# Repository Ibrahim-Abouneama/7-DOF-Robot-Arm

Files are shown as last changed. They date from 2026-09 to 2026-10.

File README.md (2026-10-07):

# 🦾 7-DOF Robot Arm Hotkey & Web Controller

A high-performance robotic arm control suite featuring zero-glitch ESP32 firmware, linear slew motion profiling, browser-based hotkey control (USB WebSerial), and complete 3D CAD models.

---

## 🌟 Highlights

- **Zero-Glitch Direct PCA9685 Driver**: Custom bare-metal I2C driver eliminating comparator glitches, phase-staggered pulse timing to prevent peak power surges, and automatic register recovery without resetting joint positions.
- **Linear Slew Profile**: Smooth, non-blocking motion ramping at user-selectable speeds (20°/s to 120°/s) to protect gearboxes and eliminate jerks.
- **Dual Connectivity Modes**:
  - **USB Mode**: Direct low-latency WebSerial communication via Chrome/Edge/Opera.
- **Full Keyboard Hotkeys**: Control all 6 axes + claw simultaneously with configurable step sizes and continuous drive.
- **Complete CAD Package**: Includes 12 universal 3D-printable `.STEP` models and the SolidWorks master assembly (`RobotArm_Assembly.SLDASM`).

---

## 📂 Repository Structure

```text
├── cad/
│   ├── assembly/
│   │   └── RobotArm_Assembly.SLDASM    # SolidWorks master assembly
│   └── step/                           # 12 3D-printable STEP models
│       ├── Base.STEP
│       ├── Claw.STEP
│       ├── Claw 1.STEP
│       ├── Claw Holder.STEP
│       ├── Claw Link.STEP
│       ├── Gear.STEP
│       ├── Gear 1.STEP
│       ├── Rod 0.STEP
│       ├── Rod 1.STEP
│       ├── Rod2.STEP
│       ├── Shoulder.STEP
│       └── Wrist.STEP
├── firmware/
│   └── robot_arm_v3/                   # USB WebSerial firmware
│       └── robot_arm_v3.ino
├── controller/
│   └── servo_hotkeys_v2.html           # USB WebSerial controller UI
├── start_hotkey_controller.bat         # 1-click launcher for USB mode
├── .gitignore
└── README.md
```

---

## ⚡ Hardware & Wiring

### Components
- **Microcontroller**: ESP32 Development Board (30-pin or 38-pin)
- **PWM Driver**: PCA9685 16-Channel 12-Bit I2C Servo Driver
- **Servos**: MG996R / MG995 (High-Torque for Base, Shoulder, Elbow) + SG90 (Wrist & Gripper)
- **Power Supply**: Dedicated 5V-6V 4A-10A DC Power Supply (connected to PCA9685 green terminal)

> ⚠️ **Warning**: Never power the servos from the ESP32 5V/3.3V pins. Always use a dedicated power supply for the PCA9685 screw terminal with common GND shared with the ESP32.

### Pinout
| ESP32 Pin | PCA9685 Pin | Description |
|---|---|---|
| **GPIO 21** | **SDA** | I2C Data Line |
| **GPIO 22** | **SCL** | I2C Clock Line |
| **3V3** | **VCC** | Logic Power (3.3V) |
| **GND** | **GND** | Common Ground |
| — | **V+ (Terminal)** | 5V - 6V DC High-Current Power |

### Servo Channels & Calibrated Defaults
| PCA9685 Channel | Joint Name | Min Limit | Max Limit | Home Angle | Typical Servo |
|:---:|---|:---:|:---:|:---:|:---:|
| **CH 15** | Base Rotation | 0° | 180° | **90°** | MG996R |
| **CH 14** | Shoulder Pitch | 10° | 170° | **44°** | MG996R |
| **CH 13** | Elbow Pitch | 10° | 170° | **130°** | MG996R |
| **CH 12** | Forearm Pitch | 10° | 170° | **90°** | MG996R / SG90 |
| **CH 11** | Wrist Roll | 0° | 180° | **90°** | SG90 |
| **CH 10** | Wrist Pitch | 10° | 170° | **90°** | SG90 |
| **CH 9** | Gripper Claw | 0° | 90° | **0°** (Open) | SG90 |

---

## ⌨️ Keyboard Hotkey Map
| Key Binding | Function | Direction / Action |
|:---:|---|---|
| <kbd>Q</kbd> / <kbd>A</kbd> | Base Yaw | Rotate Left / Right |
| <kbd>W</kbd> / <kbd>S</kbd> | Shoulder | Tilt Up / Down |
| <kbd>E</kbd> / <kbd>D</kbd> | Elbow | Tilt Up / Down |
| <kbd>R</kbd> / <kbd>F</kbd> | Forearm | Tilt Up / Down |
| <kbd>T</kbd> / <kbd>G</kbd> | Wrist Roll | Rotate CW / CCW |
| <kbd>Y</kbd> / <kbd>H</kbd> | Wrist Pitch | Tilt Up / Down |
| <kbd>U</kbd> / <kbd>J</kbd> | Gripper | Close / Open Claw |
| <kbd>←</kbd> / <kbd>→</kbd> | Active ch nudge | Nudge Selected Joint (− / +) |
| <kbd>[</kbd> / <kbd>]</kbd> | Step size | Cycle Step Size (1°, 5°, 10°, 20°) |
| <kbd>Space</kbd> | Home pose | Auto-align arm to default posture |
| <kbd>1</kbd> – <kbd>7</kbd> | Select ch | Select Active Joint (CH 15 to CH 9) |
| <kbd>Esc</kbd> | **E-Stop** | Instantly freeze all joints / Toggle resume |

---

## 🚀 Getting Started

### 1. Flash the ESP32 Firmware
1. Open the [Arduino IDE](https://www.arduino.cc/en/software).
2. Install the **esp32** board package (`Tools` > `Board` > `Boards Manager...`).
3. Select your ESP32 board and COM port.
4. Open:
   - `firmware/robot_arm_v3/robot_arm_v3.ino` (for USB WebSerial)
5. Click **Upload**.

### 2. Launch the Controller

1. Connect ESP32 to your PC via USB.
2. Double-click `start_hotkey_controller.bat` (opens `controller/servo_hotkeys_v2.html` in Chrome/Edge/Opera).
3. Click **Connect Serial**, select your ESP32 COM port (115200 baud).
4. Use your keyboard or on-screen sliders to control the arm.

---

## 🖨️ 3D Printing & CAD

All 12 `.STEP` models in `cad/step/` can be directly imported into any modern slicer:
- **Recommended Material**: PLA+ or PETG
- **Infill**: 30% - 50% Gyroid or Grid (higher infill recommended for `Base.STEP`, `Shoulder.STEP`, and `Rod 0.STEP`)
- **Perimeters/Walls**: 4-5 walls for structural rigidity
- **Assembly CAD**: `cad/assembly/RobotArm_Assembly.SLDASM` can be opened in Dassault Systèmes SolidWorks.

---

## 📄 License

MIT License. Free to use, modify, and distribute for personal and commercial robotics projects.

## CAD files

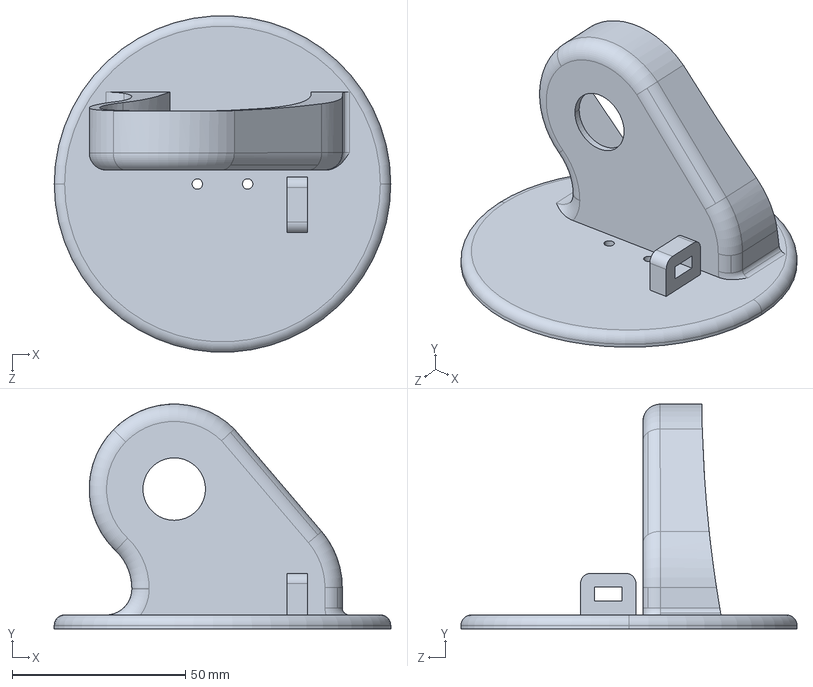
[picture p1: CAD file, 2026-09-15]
cad/step/Shoulder.STEP
97.0 x 64.7 x 96.8 mm

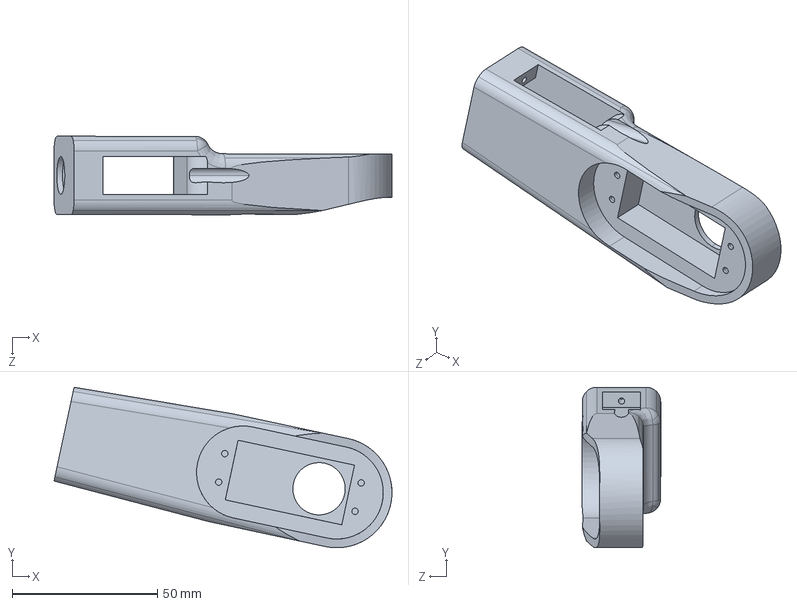
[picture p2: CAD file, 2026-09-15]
cad/step/Rod2.STEP
116.3 x 55.2 x 27.0 mm

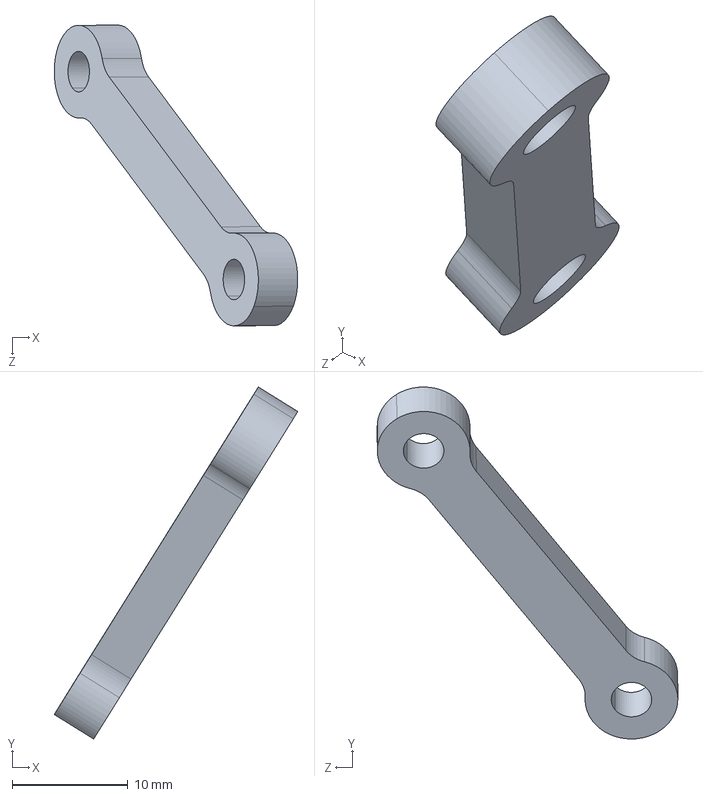
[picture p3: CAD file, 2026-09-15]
cad/step/Claw Link.STEP
21.0 x 30.4 x 25.9 mm

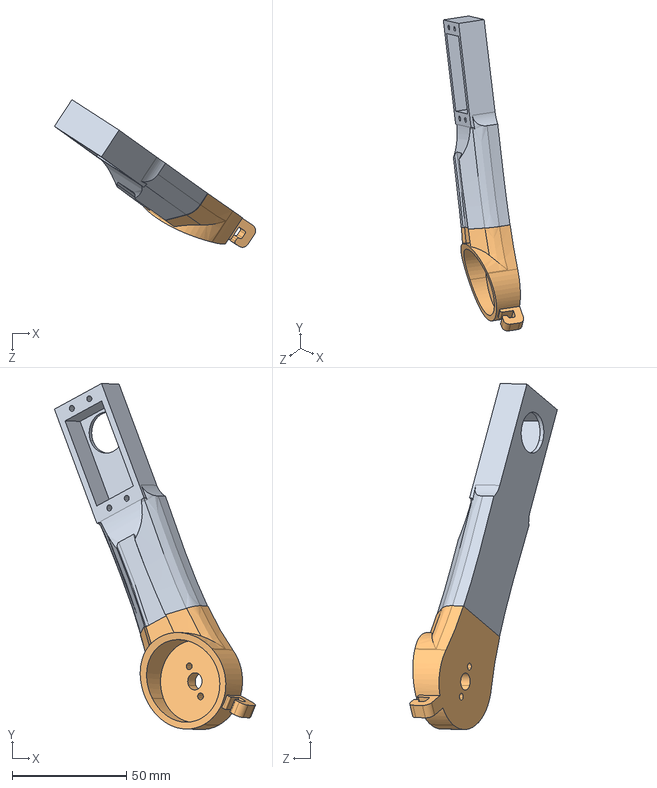
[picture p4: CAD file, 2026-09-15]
cad/step/Rod 0.STEP
88.1 x 151.4 x 64.6 mm

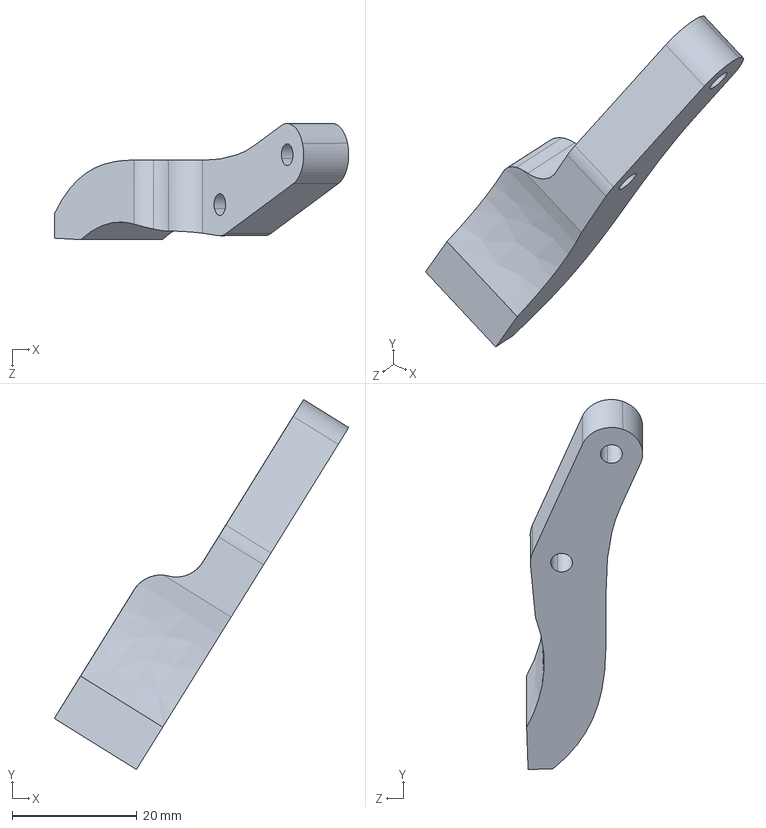
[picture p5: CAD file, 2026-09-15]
cad/step/Claw.STEP
47.2 x 59.3 x 18.6 mm

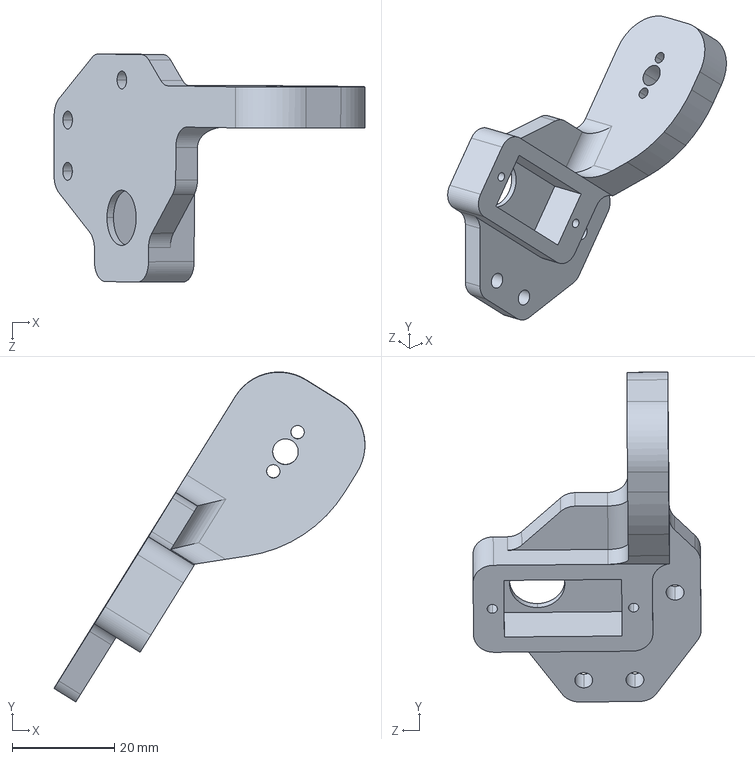
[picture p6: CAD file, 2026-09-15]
cad/step/Claw Holder.STEP
60.7 x 64.4 x 44.5 mm

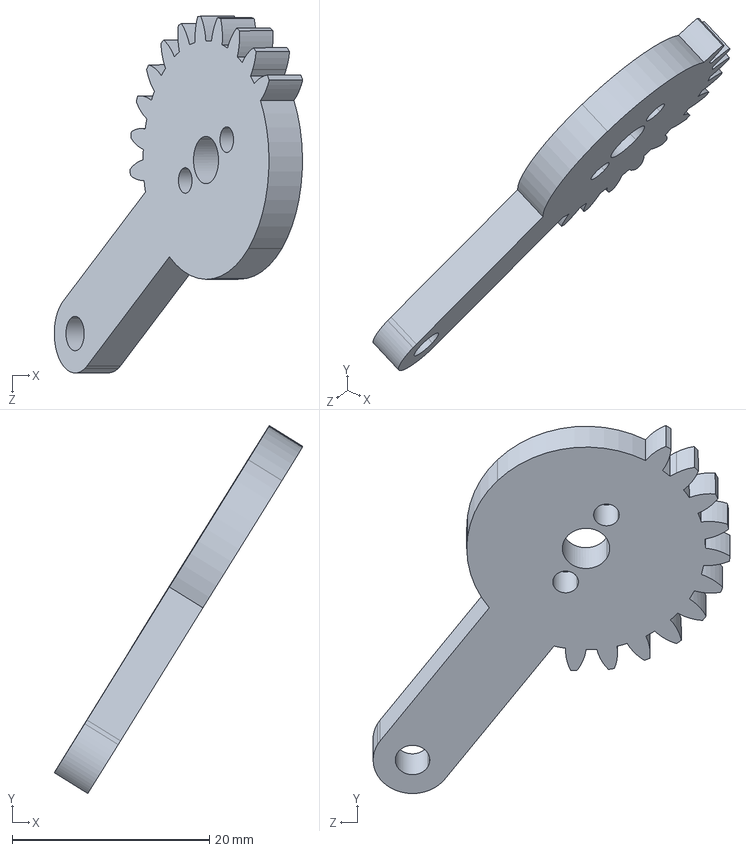
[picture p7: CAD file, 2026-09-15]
cad/step/Gear.STEP
25.2 x 37.3 x 36.2 mm

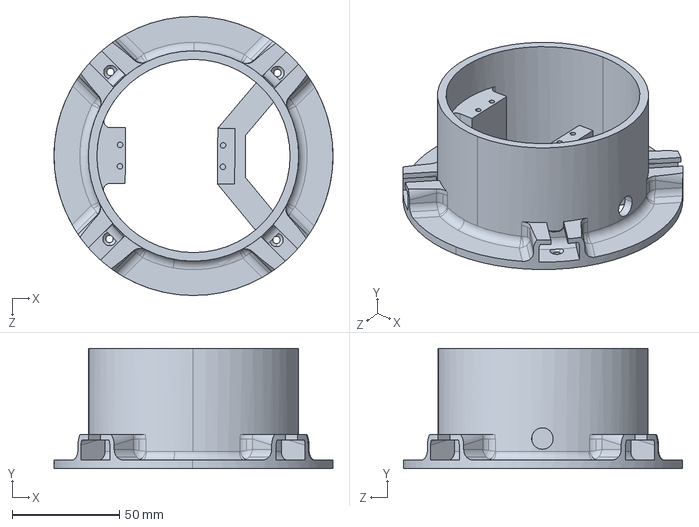
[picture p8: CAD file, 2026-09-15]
cad/step/Base.STEP
130.0 x 56.0 x 130.0 mm

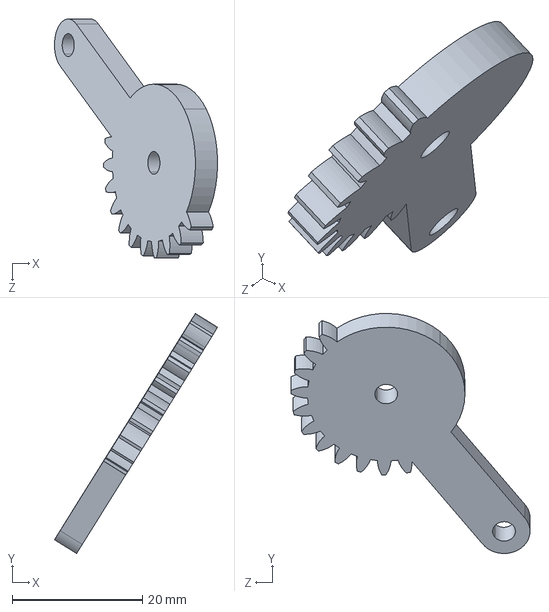
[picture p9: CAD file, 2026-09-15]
cad/step/Gear 1.STEP
25.0 x 36.9 x 36.7 mm

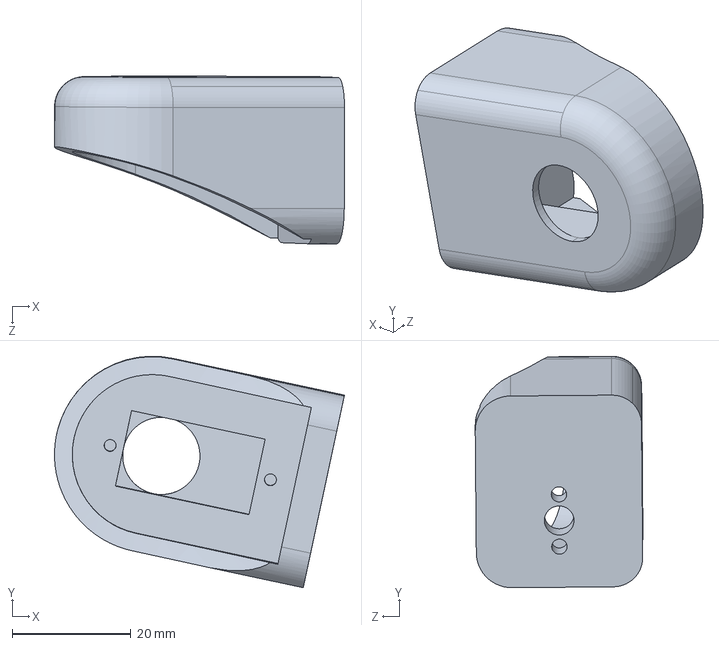
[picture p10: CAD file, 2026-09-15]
cad/step/Wrist.STEP
48.8 x 38.9 x 28.2 mm

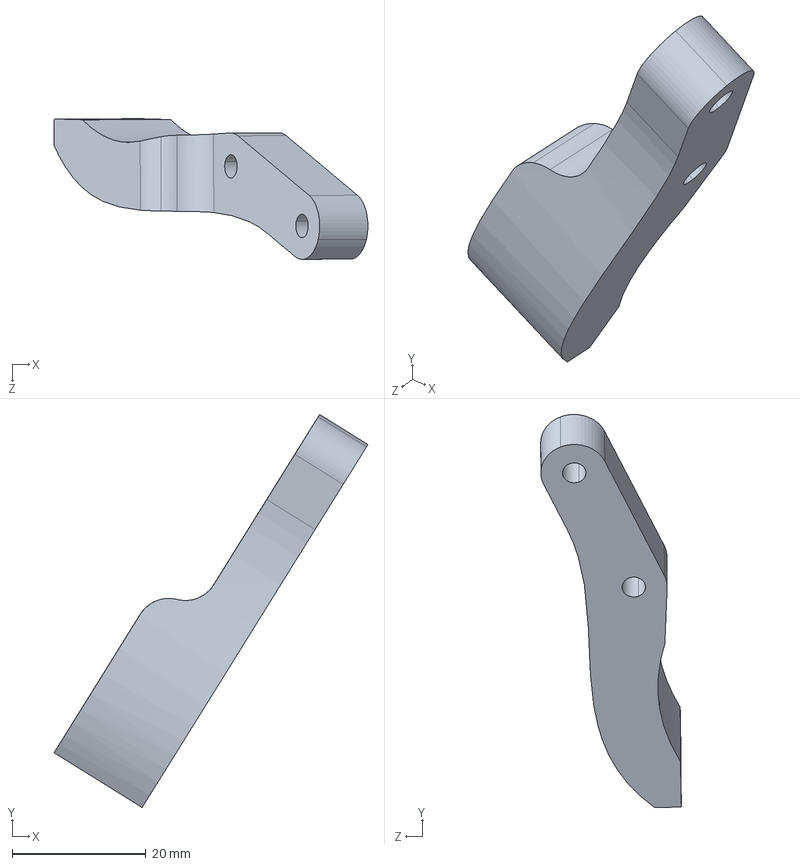
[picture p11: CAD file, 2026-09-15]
cad/step/Claw 1.STEP
46.9 x 58.8 x 21.0 mm

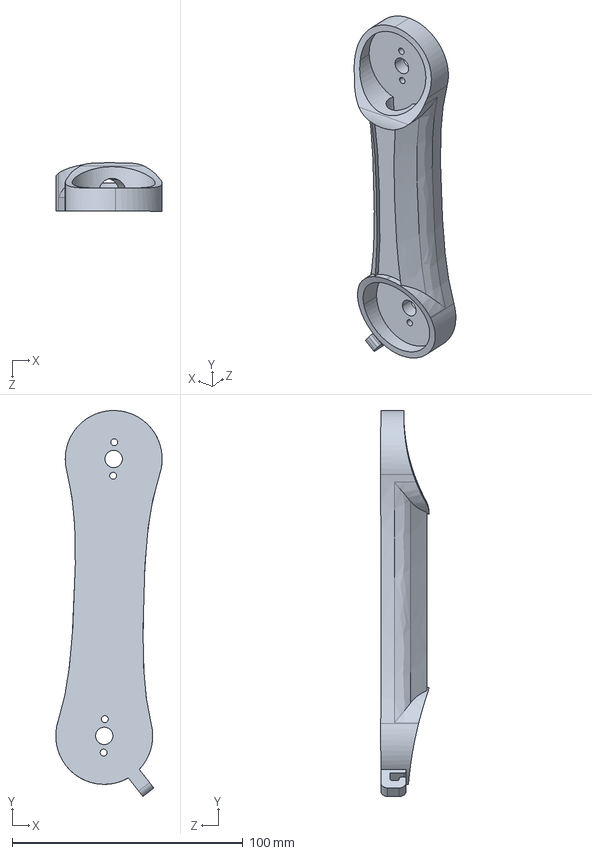
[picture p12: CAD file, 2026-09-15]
cad/step/Rod 1.STEP
46.1 x 167.2 x 21.0 mm

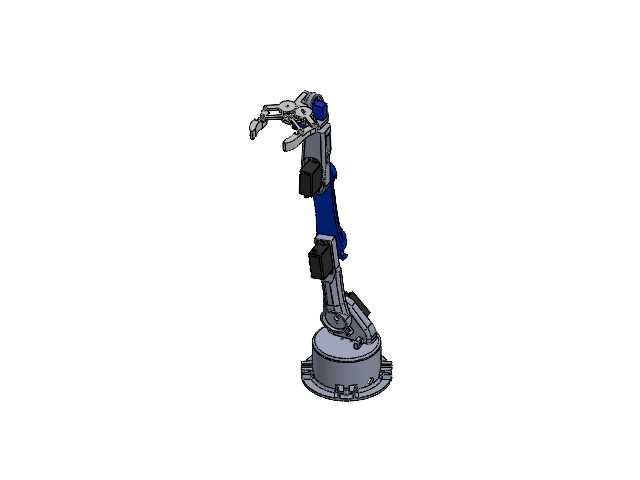
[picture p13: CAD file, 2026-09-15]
cad/assembly/RobotArm_Assembly.SLDASM
MG996R Servo
SG90
SG90 1
MG996R Servo 1 x 2
MG996R Servo 2
SG90 2
Claw
Claw Link x 2
Gear
Claw Holder
Claw 1
Gear 1
Base
Wrist
Rod2
Rod 1
Pin
Shoulder
Rod 0

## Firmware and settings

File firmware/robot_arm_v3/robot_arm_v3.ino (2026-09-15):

// ============================================================================
//  ESP32 ROBOT ARM CONTROLLER v3.0 — GROUND-UP REBUILD
//  Channels: 15 (Base) → 9 (Gripper)
//  Protocol: $CMD,arg1,arg2*\n  (115200 baud)
//  Driver:   Direct PCA9685 register access via Wire.h — ZERO external libs
// ============================================================================
//
//  HARDWARE WIRING:
//    ESP32 GPIO 21 (SDA) → PCA9685 SDA
//    ESP32 GPIO 22 (SCL) → PCA9685 SCL
//    ESP32 GND            → PCA9685 GND  → Power Supply GND (common ground!)
//    Power Supply 5-6V    → PCA9685 V+ screw terminal
//    PCA9685 OE pin       → GND (active low = outputs enabled)
//
//  CHANNEL MAP:
//    CH 15: Base Turntable Yaw       (MG996R)   0-180°
//    CH 14: Shoulder Pitch (Grey)    (MG996R)  10-170°
//    CH 13: Elbow Pitch (Blue)       (MG996R)  10-170°
//    CH 12: Forearm Pitch (Grey)     (MG996R)  10-170°
//    CH 11: Wrist Roll              (MG90S)    0-180°
//    CH 10: Wrist Pitch             (MG90S)   10-170°
//    CH  9: Gripper Claw            (SG90)     0-90°
// ============================================================================

#include <Wire.h>

// ─── Pin & Address Configuration ────────────────────────────────────────────
#define I2C_SDA       21
#define I2C_SCL       22
#define PCA_ADDR      0x40

// ─── PCA9685 Registers ─────────────────────────────────────────────────────
#define REG_MODE1     0x00
#define REG_MODE2     0x01
#define REG_LED0_ON_L 0x06
#define REG_PRESCALE  0xFE

// ─── PCA9685 Bits ───────────────────────────────────────────────────────────
#define MODE1_AI      0x20    // Auto-increment
#define MODE1_SLEEP   0x10    // Sleep (must set to change prescaler)
#define MODE1_ALLCALL 0x01    // Respond to all-call address
#define MODE2_OUTDRV  0x04    // Totem-pole outputs
// OCH bit = 0 (default) → outputs update on I2C STOP, not ACK = atomic

// ─── Servo PWM Calibration (50 Hz = 20ms period, 12-bit = 4096 ticks) ─────
//  0°   → ~500µs  → 500/20000 * 4096 ≈ 102 ticks
//  180° → ~2500µs → 2500/20000 * 4096 ≈ 512 ticks
#define TICK_MIN      102
#define TICK_MAX      512
#define TICK_CENTER   307

// ─── Arm Channel Definitions ───────────────────────────────────────────────
#define NUM_JOINTS    7

// Index 0=Base(CH15), 1=Shoulder(CH14), ... 6=Gripper(CH9)
const uint8_t jointChannel[NUM_JOINTS] = {15, 14, 13, 12, 11, 10, 9};
const int     jointMin[NUM_JOINTS]     = { 0, 10, 10, 10,  0, 10,  0};
const int     jointMax[NUM_JOINTS]     = {180,170,170,170,180,170, 90};
// Default Home pose matching default.png: CH15=90, CH14=90, CH13=60, CH12=170, CH11=90, CH10=125, CH9=45
const int     jointDefault[NUM_JOINTS] = {90, 90, 60, 170, 90, 125, 45};

// ─── Servo State ────────────────────────────────────────────────────────────
float currentAngle[NUM_JOINTS];     // Smoothly interpolated current position
int   targetAngle[NUM_JOINTS];      // Commanded target position
bool  jointEnabled[NUM_JOINTS];     // Is this joint actively driven?
int   lastWrittenTicks[NUM_JOINTS]; // Cache: last tick value written to PCA9685
                                    // Only re-write when this changes → eliminates
                                    // redundant I2C traffic that causes bus noise

// ─── Slew Rate Limiter ──────────────────────────────────────────────────────
#define SLEW_INTERVAL_MS  20        // 20ms = 50Hz (synchronized to PCA9685 50Hz PWM frame rate)
float slewStepDeg = 1.6f;           // Degrees per 20ms tick (1.6° = 80°/sec, fast & responsive)
unsigned long lastSlewMs = 0;

// ─── Watchdog ───────────────────────────────────────────────────────────────
#define WATCHDOG_INTERVAL_MS 5000
unsigned long lastWatchdogMs = 0;
bool slewActive = false;            // Flag to avoid I2C collision with watchdog

// ─── Non-blocking Sweep State Machine ───────────────────────────────────────
bool sweepRunning = false;
int  sweepJointIdx = -1;
int  sweepAngle = 0;
int  sweepDir = 1;                  // +1 going up, -1 going down, 0 = done
int  sweepPhase = 0;                // 0=up, 1=down, 2=center, 3=done
unsigned long lastSweepMs = 0;
#define SWEEP_STEP_MS 30

// ─── E-Stop ─────────────────────────────────────────────────────────────────
bool frozen = false;


// ============================================================================
//  SECTION A: MINIMAL PCA9685 DRIVER
// ============================================================================

// 9-clock bus recovery for hung I2C slaves
void pca_busRecover() {
  Wire.end();
  pinMode(I2C_SDA, INPUT_PULLUP);
  pinMode(I2C_SCL, OUTPUT);

  for (int i = 0; i < 9; i++) {
    digitalWrite(I2C_SCL, HIGH);
    delayMicroseconds(5);
    digitalWrite(I2C_SCL, LOW);
    delayMicroseconds(5);
  }
  // STOP condition
  pinMode(I2C_SDA, OUTPUT);
  digitalWrite(I2C_SDA, LOW);
  delayMicroseconds(5);
  digitalWrite(I2C_SCL, HIGH);
  delayMicroseconds(5);
  digitalWrite(I2C_SDA, HIGH);
  delayMicroseconds(5);

  // Re-init Wire
  Wire.begin(I2C_SDA, I2C_SCL);
  Wire.setClock(100000);
  Wire.setTimeOut(50);
}

// Write a single register byte
bool pca_writeReg(uint8_t reg, uint8_t val) {
  Wire.beginTransmission(PCA_ADDR);
  Wire.write(reg);
  Wire.write(val);
  return (Wire.endTransmission() == 0);
}

// Read a single register byte
uint8_t pca_readReg(uint8_t reg) {
  Wire.beginTransmission(PCA_ADDR);
  Wire.write(reg);
  if (Wire.endTransmission(false) != 0) return 0xFF;
  Wire.requestFrom((uint8_t)PCA_ADDR, (uint8_t)1);
  return Wire.available() ? Wire.read() : 0xFF;
}

// Atomic 4-byte burst write: ON_L, ON_H, OFF_L, OFF_H
// Auto-increment (AI bit in MODE1) advances the register pointer automatically
bool pca_write4(uint8_t ch, uint16_t onTime, uint16_t offTime) {
  if (ch > 15) return false;

  for (int attempt = 0; attempt < 3; attempt++) {
    Wire.beginTransmission(PCA_ADDR);
    Wire.write(REG_LED0_ON_L + (ch * 4));
    Wire.write((uint8_t)(onTime & 0xFF));
    Wire.write((uint8_t)((onTime >> 8) & 0x0F));
    Wire.write((uint8_t)(offTime & 0xFF));
    Wire.write((uint8_t)((offTime >> 8) & 0x0F));
    uint8_t err = Wire.endTransmission();

    if (err == 0) return true;

    delayMicroseconds(100);
    if (attempt == 1) {
      Serial.printf("[I2C] Retry failed on CH%d, recovering bus...\n", ch);
      pca_busRecover();
    }
  }

  Serial.printf("[I2C FAIL] CH%d write failed after 3 attempts!\n", ch);
  return false;
}

// Set channel to full-off (0% duty, no holding current)
void pca_fullOff(uint8_t ch) {
  if (ch > 15) return;
  Wire.beginTransmission(PCA_ADDR);
  Wire.write(REG_LED0_ON_L + (ch * 4));
  Wire.write(0x00);  // ON_L
  Wire.write(0x00);  // ON_H
  Wire.write(0x00);  // OFF_L
  Wire.write(0x10);  // OFF_H bit4 = FULL_OFF
  Wire.endTransmission();
}

// Check if PCA9685 is alive and awake
bool pca_alive() {
  uint8_t mode1 = pca_readReg(REG_MODE1);
  if (mode1 == 0xFF) return false;          // I2C read failed entirely
  if (mode1 & MODE1_SLEEP) return false;    // Chip fell asleep (brownout?)
  if (!(mode1 & MODE1_AI)) return false;    // Auto-increment got cleared
  return true;
}

// Full cold-start initialization
bool pca_init() {
  pca_busRecover();
  Wire.begin(I2C_SDA, I2C_SCL);
  Wire.setClock(100000);
  Wire.setTimeOut(50);

  // Verify device present
  Wire.beginTransmission(PCA_ADDR);
  if (Wire.endTransmission() != 0) {
    Serial.println("[ERROR] PCA9685 not found at 0x40!");
    return false;
  }

  // Reset
  pca_writeReg(REG_MODE1, 0x00);
  delay(10);

  // Sleep → set prescaler → wake
  pca_writeReg(REG_MODE1, MODE1_SLEEP);
  delay(5);
  pca_writeReg(REG_PRESCALE, 121);   // 50 Hz: round(25MHz / (4096 × 50)) - 1
  delay(5);
  pca_writeReg(REG_MODE1, MODE1_AI | MODE1_ALLCALL);  // Wake with auto-increment
  delay(5);

  // MODE2: totem-pole, OCH=0 (update on STOP = atomic)
  pca_writeReg(REG_MODE2, MODE2_OUTDRV);
  delay(5);

  Serial.println("[PCA] Initialized: 50Hz, AI=1, OUTDRV=1, OCH=0");
  return true;
}

// Recovery: re-init registers WITHOUT resetting servo positions
// This is the KEY fix for the "shoulder full send" bug.
// Old code called pca_init() which reset everything to 90°.
// This version preserves currentAngle[] and re-applies them.
void pca_recover() {
  Serial.println("[WATCHDOG] PCA9685 anomaly detected — recovering registers...");

  pca_busRecover();
  Wire.begin(I2C_SDA, I2C_SCL);
  Wire.setClock(100000);
  Wire.setTimeOut(50);

  // Re-init mode registers only
  pca_writeReg(REG_MODE1, MODE1_SLEEP);
  delay(5);
  pca_writeReg(REG_PRESCALE, 121);
  delay(5);
  pca_writeReg(REG_MODE1, MODE1_AI | MODE1_ALLCALL);
  delay(5);
  pca_writeReg(REG_MODE2, MODE2_OUTDRV);
  delay(5);

  // Re-apply CURRENT angles (not defaults!) with staggered timing
  for (int i = 0; i < NUM_JOINTS; i++) {
    if (jointEnabled[i]) {
      servo_applyHardware(i);
      delay(20);
    }
  }

  Serial.println("[WATCHDOG] Recovery complete — angles preserved.");
}


// ============================================================================
//  SECTION B: SERVO ABSTRACTION LAYER
// ============================================================================

// Convert degrees (0-180) to PCA9685 ticks
int servo_degreesToTicks(int deg) {
  deg = constrain(deg, 0, 180);
  return map(deg, 0, 180, TICK_MIN, TICK_MAX);
}

// Apply current angle for joint[index] to hardware
// ONLY writes to PCA9685 if the tick value actually changed (tick cache)
void servo_applyHardware(int idx) {
  if (idx < 0 || idx >= NUM_JOINTS || !jointEnabled[idx]) return;

  uint8_t ch = jointChannel[idx];
  int ticks = servo_degreesToTicks((int)round(currentAngle[idx]));

  // Skip write if tick value hasn't changed
  if (ticks == lastWrittenTicks[idx]) return;
  lastWrittenTicks[idx] = ticks;

  // onTime is ALWAYS 0 for standard RC servo PWM.
  // Phase-staggering caused catastrophic comparator-miss glitches in PCA9685:
  // if an I2C update arrives while counter is near onTime/offTime, the output
  // misses the match and stays HIGH for an entire 4096-tick (20ms) cycle!
  // That 20ms full-duty pulse causes the servo to violently jerk and spike current.
  // With onTime = 0, the active pulse is strictly within ticks 0..512 (first 2.5ms).
  // The remaining 17.5ms of every 20ms frame is 100% LOW, allowing completely glitch-free updates.
  pca_write4(ch, 0, (uint16_t)ticks);
}

// Set target angle for a joint (clamped to limits)
void servo_setTarget(int idx, int angle) {
  if (idx < 0 || idx >= NUM_JOINTS) return;
  if (frozen) return;   // Ignore commands while E-stopped

  angle = constrain(angle, jointMin[idx], jointMax[idx]);
  targetAngle[idx] = angle;
  jointEnabled[idx] = true;
}

// Get current rounded angle for a joint
int servo_getAngle(int idx) {
  if (idx < 0 || idx >= NUM_JOINTS) return 90;
  return (int)round(currentAngle[idx]);
}

// Map PCA9685 channel number (9-15) to joint index (0-6), returns -1 if invalid
int channelToIndex(int ch) {
  for (int i = 0; i < NUM_JOINTS; i++) {
    if (jointChannel[i] == ch) return i;
  }
  return -1;
}

// Slew rate tick: call every SLEW_INTERVAL_MS. Smoothly ramps current → target.
// Linear rate: advances at a constant, responsive speed without sluggish crawling tails.
void servo_slewTick() {
  slewActive = false;

  for (int i = 0; i < NUM_JOINTS; i++) {
    if (!jointEnabled[i]) continue;

    float diff = (float)targetAngle[i] - currentAngle[i];
    float absDiff = fabs(diff);

    if (absDiff < 0.05f) continue;    // Already at target, skip

    slewActive = true;

    // Linear step: constant speed up to target, no creeping or dragging
    float step = (absDiff < slewStepDeg) ? absDiff : slewStepDeg;

    if (diff > 0) {
      currentAngle[i] += step;
    } else {
      currentAngle[i] -= step;
    }

    servo_applyHardware(i);
  }
}

// E-Stop: freeze all joints at their current positions
void servo_freezeAll() {
  frozen = true;
  for (int i = 0; i < NUM_JOINTS; i++) {
    targetAngle[i] = (int)round(currentAngle[i]);
  }
  Serial.println("[ESTOP] All joints frozen at current positions.");
}

// Unfreeze: resume accepting commands
void servo_unfreeze() {
  frozen = false;
  Serial.println("[ESTOP] Unfrozen — accepting commands.");
}

// Disable all PWM outputs (full-off, no holding torque)
void servo_disableAll() {
  for (int i = 0; i < NUM_JOINTS; i++) {
    pca_fullOff(jointChannel[i]);
    jointEnabled[i] = false;
    lastWrittenTicks[i] = -1;  // Invalidate cache so re-enable writes fresh
  }
  Serial.println("[OFF] All PWM outputs disabled.");
}

// Re-enable all joints and apply current angles
void servo_enableAll() {
  for (int i = 0; i < NUM_JOINTS; i++) {
    jointEnabled[i] = true;
    servo_applyHardware(i);
    delay(20);
  }
  Serial.println("[ON] All joints re-enabled at current angles.");
}

// Center all joints to their defaults (used at startup)
void servo_centerAll() {
  for (int i = 0; i < NUM_JOINTS; i++) {
    currentAngle[i] = (float)jointDefault[i];
    targetAngle[i] = jointDefault[i];
    jointEnabled[i] = true;
    servo_applyHardware(i);
    delay(35);    // Stagger power-up to reduce inrush current
  }
}


// ============================================================================
//  SECTION C: SERIAL COMMAND PARSER (Non-blocking FSM)
// ============================================================================

enum ParseState { PS_IDLE, PS_CMD, PS_ARG1, PS_ARG2 };

ParseState ps = PS_IDLE;
char cmdBuf[8];   int cmdLen = 0;
char arg1Buf[8];  int arg1Len = 0;
char arg2Buf[8];  int arg2Len = 0;

void resetParser() {
  ps = PS_IDLE;
  cmdLen = 0;
  arg1Len = 0;
  arg2Len = 0;
}

// Execute parsed command
void executeCommand() {
  cmdBuf[cmdLen] = '\0';
  arg1Buf[arg1Len] = '\0';
  arg2Buf[arg2Len] = '\0';

  // ── $SET,<ch>,<angle>* ──
  if (strcasecmp(cmdBuf, "SET") == 0) {
    int ch = atoi(arg1Buf);
    int angle = atoi(arg2Buf);
    int idx = channelToIndex(ch);
    if (idx >= 0 && angle >= 0 && angle <= 180) {
      servo_setTarget(idx, angle);
      Serial.printf("ACK:%d:%d\n", ch, targetAngle[idx]);
    } else {
      Serial.printf("ERR:SET:bad_args ch=%d angle=%d\n", ch, angle);
    }
    return;
  }

  // ── $ALL,<angle>* ── (FIX: angle is in arg1, not arg2!)
  if (strcasecmp(cmdBuf, "ALL") == 0) {
    int angle = atoi(arg1Buf);    // ← THIS WAS THE BUG: v2 read arg2 (empty=0)
    if (angle >= 0 && angle <= 180) {
      for (int i = 0; i < NUM_JOINTS; i++) {
        servo_setTarget(i, angle);
      }
      Serial.printf("ACK:ALL:%d\n", angle);
    } else {
      Serial.printf("ERR:ALL:bad_angle %d\n", angle);
    }
    return;
  }

  // ── $HOME* ── (Move all joints to default Home pose from default.png)
  if (strcasecmp(cmdBuf, "HOME") == 0) {
    for (int i = 0; i < NUM_JOINTS; i++) {
      servo_setTarget(i, jointDefault[i]);
    }
    Serial.println("ACK:HOME");
    return;
  }

  // ── $STOP* ── (E-Stop)
  if (strcasecmp(cmdBuf, "STOP") == 0) {
    servo_freezeAll();
    Serial.println("ACK:STOP");
    return;
  }

  // ── $GO* ── (Unfreeze)
  if (strcasecmp(cmdBuf, "GO") == 0) {
    servo_unfreeze();
    Serial.println("ACK:GO");
    return;
  }

  // ── $OFF* ── (Disable all PWM)
  if (strcasecmp(cmdBuf, "OFF") == 0) {
    servo_disableAll();
    Serial.println("ACK:OFF");
    return;
  }

  // ── $ON* ── (Re-enable all PWM)
  if (strcasecmp(cmdBuf, "ON") == 0) {
    servo_enableAll();
    Serial.println("ACK:ON");
    return;
  }

  // ── $ISO,<ch>* ── (Isolate: enable one channel at 90°, full-off all others)
  if (strcasecmp(cmdBuf, "ISO") == 0) {
    int ch = atoi(arg1Buf);
    int idx = channelToIndex(ch);
    if (idx >= 0) {
      Serial.printf("[DIAG] Isolating CH%d, disabling others...\n", ch);
      for (int i = 0; i < NUM_JOINTS; i++) {
        if (i == idx) {
          currentAngle[i] = 90.0f;
          targetAngle[i] = 90;
          jointEnabled[i] = true;
          servo_applyHardware(i);
        } else {
          pca_fullOff(jointChannel[i]);
          jointEnabled[i] = false;
          lastWrittenTicks[i] = -1;
        }
      }
      Serial.printf("ACK:ISO:%d\n", ch);
    } else {
      Serial.printf("ERR:ISO:bad_ch %d\n", ch);
    }
    return;
  }

  // ── $QUERY* ── (Report all current angles)
  if (strcasecmp(cmdBuf, "QUERY") == 0) {
    Serial.print("POS");
    for (int i = 0; i < NUM_JOINTS; i++) {
      Serial.printf(":%d:%d", jointChannel[i], servo_getAngle(i));
    }
    Serial.println();
    return;
  }

  // ── $SPEED,<deg_per_sec>* ── (Adjust slew speed on the fly, e.g. $SPEED,100*)
  if (strcasecmp(cmdBuf, "SPEED") == 0) {
    int spd = atoi(arg1Buf);
    if (spd >= 10 && spd <= 500) {
      // 50 ticks per second (20ms interval) -> deg_per_tick = deg_per_sec / 50
      slewStepDeg = (float)spd / 50.0f;
      Serial.printf("ACK:SPEED:%d\n", spd);
    } else {
      Serial.printf("ERR:SPEED:range_10_500\n");
    }
    return;
  }

  // ── $SWEEP,<ch>* ── (Non-blocking sweep)
  if (strcasecmp(cmdBuf, "SWEEP") == 0) {
    int ch = atoi(arg1Buf);
    int idx = channelToIndex(ch);
    if (idx >= 0) {
      sweepJointIdx = idx;
      sweepAngle = 0;
      sweepPhase = 0;
      sweepRunning = true;
      lastSweepMs = millis();
      jointEnabled[idx] = true;
      Serial.printf("[SWEEP] Starting non-blocking sweep on CH%d...\n", ch);
      Serial.println("ACK:SWEEP:START");
    } else {
      Serial.printf("ERR:SWEEP:bad_ch %d\n", ch);
    }
    return;
  }

  // ── $RAW,<ch>,<ticks>* ── (Direct tick write)
  if (strcasecmp(cmdBuf, "RAW") == 0) {
    int ch = atoi(arg1Buf);
    int ticks = atoi(arg2Buf);
    if (ch >= 0 && ch <= 15 && ticks >= 50 && ticks <= 600) {
      int idx = channelToIndex(ch);
      if (idx >= 0) jointEnabled[idx] = true;

      pca_write4(ch, 0, (uint16_t)ticks);
      Serial.printf("ACK:RAW:%d:%d\n", ch, ticks);
    } else {
      Serial.printf("ERR:RAW:bad_args ch=%d ticks=%d\n", ch, ticks);
    }
    return;
  }

  // ── $DIAG* ── (Print diagnostic info)
  if (strcasecmp(cmdBuf, "DIAG") == 0) {
    uint8_t m1 = pca_readReg(REG_MODE1);
    uint8_t m2 = pca_readReg(REG_MODE2);
    uint8_t pre = pca_readReg(REG_PRESCALE);
    Serial.println("--- DIAGNOSTICS ---");
    Serial.printf("MODE1=0x%02X (AI=%d SLEEP=%d)\n", m1, (m1>>5)&1, (m1>>4)&1);
    Serial.printf("MODE2=0x%02X (OCH=%d OUTDRV=%d)\n", m2, (m2>>3)&1, (m2>>2)&1);
    Serial.printf("PRESCALE=%d (should be 121 for 50Hz)\n", pre);
    Serial.printf("Frozen=%d  SlewActive=%d  SweepRunning=%d\n", frozen, slewActive, sweepRunning);
    for (int i = 0; i < NUM_JOINTS; i++) {
      Serial.printf("  J%d CH%d: curr=%.1f tgt=%d en=%d lim=[%d,%d]\n",
        i, jointChannel[i], currentAngle[i], targetAngle[i],
        jointEnabled[i], jointMin[i], jointMax[i]);
    }
    Serial.println("--- END DIAG ---");
    Serial.println("ACK:DIAG");
    return;
  }

  Serial.printf("ERR:UNKNOWN_CMD '%s'\n", cmdBuf);
}

// FSM byte-by-byte parser
void parseSerialByte(char c) {
  // '$' always resets and starts a new command
  if (c == '$') {
    resetParser();
    ps = PS_CMD;
    return;
  }

  switch (ps) {
    case PS_CMD:
      if (c == ',' || c == ' ') {
        ps = PS_ARG1;
      } else if (c == '*' || c == '\n' || c == '\r') {
        // Command with zero args (e.g. $STOP*, $QUERY*, $OFF*, $ON*, $GO*)
        executeCommand();
        resetParser();
      } else if (cmdLen < 7) {
        cmdBuf[cmdLen++] = c;
      }
      break;

    case PS_ARG1:
      if (c == ',' || c == ' ') {
        ps = PS_ARG2;
      } else if (c == '*' || c == '\n' || c == '\r') {
        // Command with 1 arg (e.g. $ALL,90* or $SWEEP,15*)
        executeCommand();
        resetParser();
      } else if (arg1Len < 7) {
        arg1Buf[arg1Len++] = c;
      }
      break;

    case PS_ARG2:
      if (c == '*' || c == '\n' || c == '\r') {
        // Command with 2 args (e.g. $SET,15,90* or $RAW,15,300*)
        executeCommand();
        resetParser();
      } else if (arg2Len < 7) {
        arg2Buf[arg2Len++] = c;
      }
      break;

    case PS_IDLE:
    default:
      // Legacy support: 'C <ch> <angle>\n'
      if (c == 'C' || c == 'c') {
        resetParser();
        cmdBuf[0] = 'S'; cmdBuf[1] = 'E'; cmdBuf[2] = 'T';
        cmdLen = 3;
        ps = PS_ARG1;
      }
      break;
  }
}


// ============================================================================
//  SECTION D: NON-BLOCKING SWEEP STATE MACHINE
// ============================================================================
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
void loop() {
  // 1. Drain serial buffer through FSM parser (non-blocking)
  while (Serial.available() > 0) {
    parseSerialByte((char)Serial.read());
  }

  unsigned long now = millis();

  // 2. Slew-rate interpolator: smooth motion every 10ms
  if (now - lastSlewMs >= SLEW_INTERVAL_MS) {
    lastSlewMs = now;
    servo_slewTick();
  }

  // 3. Non-blocking sweep state machine
  sweepTick();

  // 4. Watchdog health check every 5 seconds
  //    ONLY runs when no slew is active to avoid I2C bus collision
  if (now - lastWatchdogMs >= WATCHDOG_INTERVAL_MS) {
    lastWatchdogMs = now;

    if (!slewActive && !sweepRunning) {
      if (!pca_alive()) {
        pca_recover();    // Re-init registers, PRESERVE current angles
      }
    }
  }
}
